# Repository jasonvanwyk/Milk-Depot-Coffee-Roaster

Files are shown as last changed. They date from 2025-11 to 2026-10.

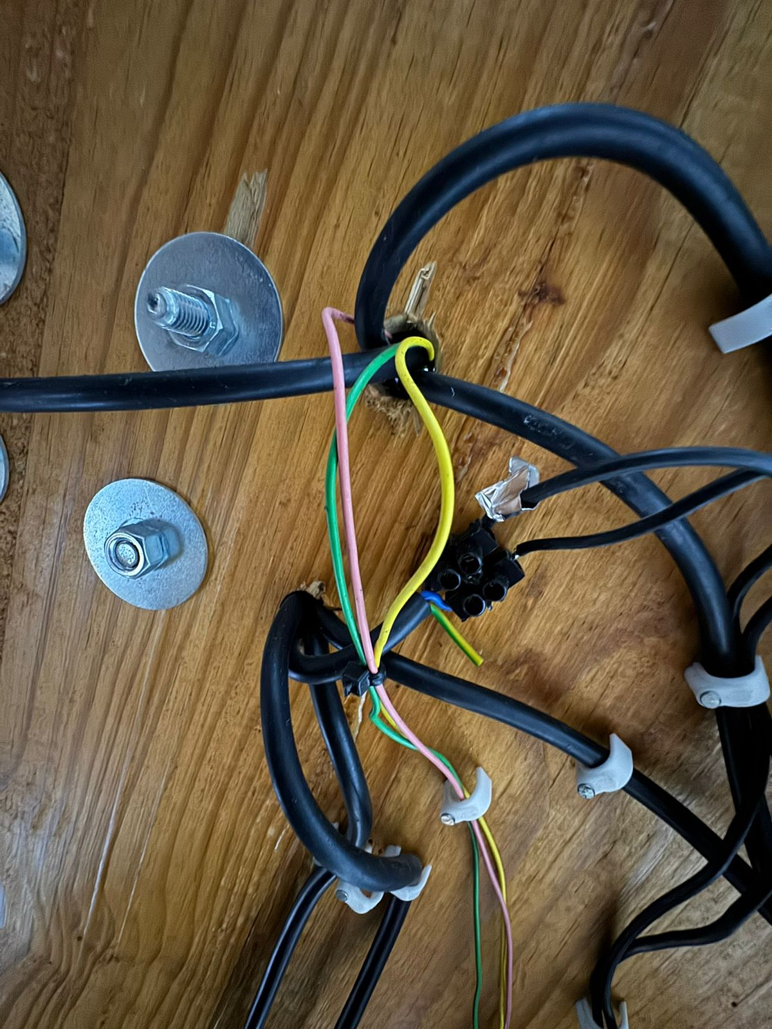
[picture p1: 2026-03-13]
pics/WhatsApp Image 2026-03-13 at 13.25.46.jpeg

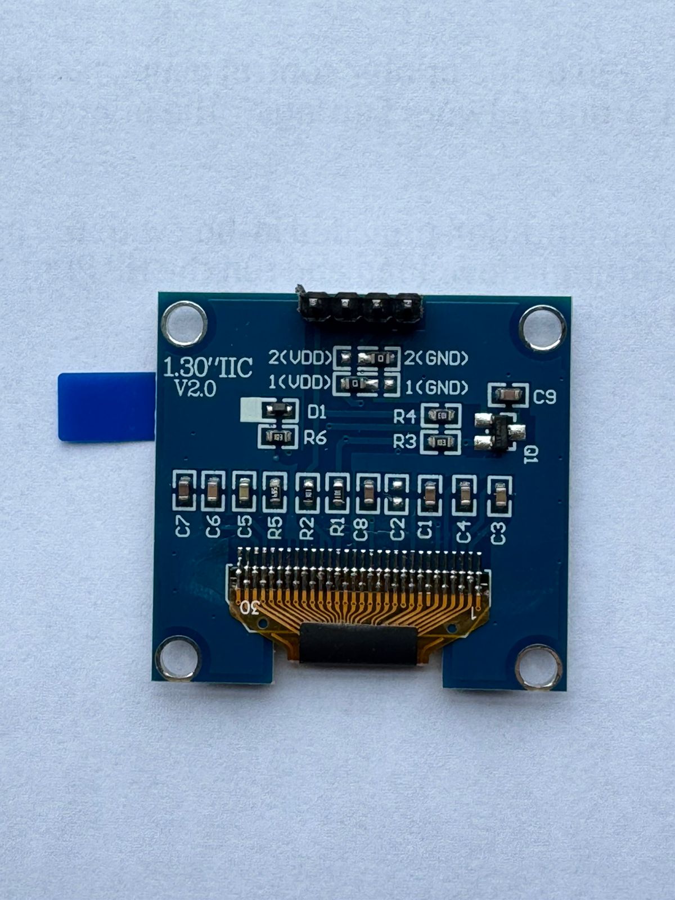
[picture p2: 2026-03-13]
pics/WhatsApp Unknown 2026-03-13 at 13.41.29/WhatsApp Image 2026-03-13 at 13.41.10.jpeg

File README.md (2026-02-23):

# Milk Depot Coffee Roaster - Precept Systems Project

## Client Information

| Field | Details |
|---|---|
| **Client Name** | Quenton (Milk Depot) |
| **Contact** | Via Jason van Wyk |
| **Project** | Coffee Roaster Temperature Monitoring System |

## Project Overview

Custom coffee roasting temperature monitoring system integrating Arduino-based 3-channel thermocouple interface with Artisan roasting software on Raspberry Pi 4. The system reads Bean Temperature (BT), Exhaust Temperature (ET), and Flame Temperature (FT) via MAX31855 amplifiers and displays real-time temperature curves with rate-of-rise calculations.

## Project Scope

1. **Arduino Firmware** - TC4 protocol emulator for 3-channel MAX31855 thermocouple reading
2. **Hardware Integration** - 3x custom K-type thermocouple probes with compression fittings, MAX31855 amplifiers, enclosure
3. **Software Configuration** - Artisan v3.4.0 setup on Raspberry Pi 4 with ArduinoTC4 device
4. **Calibration & Testing** - Probe calibration and first test roast

## Current Status

**See `STATUS.md` for detailed task tracking and current project status.**

### Quick Status
- **Phase:** Hardware Procurement
- **Software:** Complete and tested (firmware + Artisan)
- **Hardware:** Thermocouples on order from GPA Trading (PO P00041)

### Milestones
- [x] Git repository initialized
- [x] Artisan v3.4.0 installed on Raspberry Pi
- [x] Arduino TC4 firmware written and tested
- [x] Helper scripts created (compile, upload, detect, monitor)
- [x] Documentation complete
- [x] Custom thermocouple probes ordered (GPA Trading)
- [ ] Thermocouple probes delivered
- [ ] MAX31855 modules + remaining components procured
- [ ] Hardware assembly in enclosure
- [ ] Sensor calibration
- [ ] First test roast

## Hardware Summary

| Component | Status |
|---|---|
| Raspberry Pi 4 | Owned, Artisan installed |
| Arduino UNO R3 | Owned, firmware tested |
| 3x Custom K-Type Probes | On order (GPA Trading, PO P00041) |
| 3x MAX31855 Modules | To be procured |
| ABS Enclosure | To be procured |
| SSD1306 OLED (optional) | To be procured |

## Temperature Channels

| Channel | Name | Description | Artisan Mapping |
|---|---|---|---|
| 1 | ET | Exhaust/Environment Temperature | Primary ET |
| 2 | BT | Bean Temperature | Primary BT |
| 3 | FT | Flame/Burner Temperature | Extra (ArduinoTC4_34) |

## Key Files

| File | Purpose |
|---|---|
| `STATUS.md` | **Current project status and task tracking** |
| `RESUME.md` | Quick session resume context |
| `CLAUDE.md` | AI assistant project context |
| `correspondence/` | All client/supplier correspondence |
| `docs/` | Technical documentation and planning |
| `arduino-firmware/` | Arduino sketches (TC4 emulator, temp monitor, etc.) |
| `scripts/` | Helper scripts (compile, upload, detect, monitor) |

## Documentation

All technical documentation is in `docs/`:

| Document | Description |
|---|---|
| [BOM.md](docs/BOM.md) | Bill of Materials with pricing |
| [WIRING.md](docs/WIRING.md) | Wiring diagrams and enclosure layout |
| [ARTISAN_INTEGRATION.md](docs/ARTISAN_INTEGRATION.md) | Artisan configuration guide |
| [SERIAL_PROTOCOL.md](docs/SERIAL_PROTOCOL.md) | TC4 serial communication protocol |
| [ARDUINO_CLI.md](docs/ARDUINO_CLI.md) | Arduino CLI workflow guide |
| [THERMOCOUPLE_SPEC.md](docs/THERMOCOUPLE_SPEC.md) | Thermocouple technical specification |
| [CUSTOM_TC_ORDER_SPEC.md](docs/CUSTOM_TC_ORDER_SPEC.md) | Custom order spec sent to GPA Trading |
| [SHOPPING_LIST.md](docs/SHOPPING_LIST.md) | Printable shopping list with suppliers |

## Quick Start

```bash
# Compile firmware
./scripts/compile.sh arduino-firmware/tc4_emulator

# Upload to Arduino (press RESET if needed)
./scripts/upload.sh arduino-firmware/tc4_emulator

# Monitor serial output
./scripts/monitor.sh

# Detect Arduino boards
./scripts/detect.sh
```

## Workflow Notes

1. Always update `STATUS.md` when tasks are completed or status changes
2. Correspondence goes in `correspondence/` folder with date prefix
3. Technical documents go in `docs/` folder
4. Use git commits with descriptive messages

## License

- Artisan is licensed under GPL-3.0
- This project: MIT License

## Author

Jason van Wyk (jason@precept.co.za) - Precept Systems (Pty) Ltd

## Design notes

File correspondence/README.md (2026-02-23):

# Correspondence Log - Milk Depot Coffee Roaster

## Overview

This folder contains all correspondence related to the Milk Depot Coffee Roaster project, including supplier communications and client interactions.

---

## Correspondence Index

| Date | Type | Subject | Contact | File |
|---|---|---|---|---|
| 2026-01-12 | Email | Quote request for custom K-type probes | Sam Hattingh (GPA Trading) | Gmail thread |
| 2026-01-23 | Email | Quote response + acceptance | Sam Hattingh (GPA Trading) | Gmail thread |
| 2026-02-02 | Email | PO P00041 - Thermocouple order | Sam Hattingh (GPA Trading) | Gmail thread |
| 2026-02-09 | Email | Invoice + banking details reminder | Sam Hattingh (GPA Trading) | Gmail thread |

---

## File Naming Convention

- WhatsApp: `YYYY-MM-DD_whatsapp.md`
- Email: `YYYY-MM-DD_email.md`
- Phone: `YYYY-MM-DD_phone.md`
- Site Visit: `YYYY-MM-DD_site-visit.md`
- Multi-day thread: `YYYY-MM-DD-DD_channel.md`

---

## Contact Details

### Supplier: GPA Trading
- **Contact:** Sam Hattingh
- **Email:** shattingh@gpatrading.co.za
- **Role:** Thermocouple supplier (custom K-type probes)

### Client: Milk Depot
- **Contact:** Quenton
- **Role:** Coffee roaster owner/operator

---

## Notes

- Sam prefers email communication
- Quenton communicates via Jason

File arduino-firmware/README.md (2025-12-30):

# Arduino Temperature Monitor Firmware

Custom Arduino firmware for the Milk Depot Coffee Roaster - 3-channel thermocouple interface for Artisan software.

## Overview

This firmware reads temperature from three K-type thermocouples via MAX31855 amplifier modules:

| Channel | Name | Description |
|---|---|---|
| 1 | ET | Exhaust/Environment Temperature - air leaving the drum |
| 2 | BT | Bean Temperature - probe in bean mass |
| 3 | FT | Flame Temperature - near the burner |

Temperature data is sent over USB serial to Raspberry Pi running Artisan software.

## Firmware Variants

| Sketch | Protocol | Use Case |
|---|---|---|
| `tc4_emulator/` | TC4 command/response | **Production** - Use with ArduinoTC4 device |
| `temp_monitor/` | Continuous output | Alternative - Use with External Program |
| `serial_test/` | Basic serial | Testing only |
| `blank/` | None | For easy uploads when main firmware blocks |

## Hardware Requirements

### Required Components
- Arduino UNO R3
- 3x MAX31855 thermocouple amplifier modules
- 3x K-type thermocouples (Olimex TC-K-TYPE-1.5M recommended)
- USB cable for Arduino → Raspberry Pi

### Optional
- SSD1306 OLED display (128x64, I2C) for local readout

## Wiring

### SPI Bus (Shared)
```
Arduino D13 (SCK)  ────┬──── MAX31855 #1 SCK
                       ├──── MAX31855 #2 SCK
                       └──── MAX31855 #3 SCK

Arduino D12 (MISO) ────┬──── MAX31855 #1 DO
                       ├──── MAX31855 #2 DO
                       └──── MAX31855 #3 DO
```

### Chip Select (Individual)
```
Arduino D10 ──── MAX31855 #1 CS (ET - Exhaust)
Arduino D9  ──── MAX31855 #2 CS (BT - Bean)
Arduino D8  ──── MAX31855 #3 CS (FT - Flame)
```

### Power (Shared)
```
Arduino 5V  ────┬──── All MAX31855 VCC
                └──── OLED VCC (optional)

Arduino GND ────┬──── All MAX31855 GND
                └──── OLED GND (optional)
```

### I2C for OLED (Optional)
```
Arduino A4 (SDA) ──── OLED SDA
Arduino A5 (SCL) ──── OLED SCL
```

## Installation

### 1. Install Required Libraries

Open Arduino IDE → Sketch → Include Library → Manage Libraries:

- **Adafruit MAX31855** (required)
- **Adafruit BusIO** (dependency)
- **Adafruit SSD1306** (optional, for OLED)
- **Adafruit GFX Library** (optional, for OLED)

### 2. Enable Hardware Support

Edit `tc4_emulator.ino` (or `temp_monitor.ino`):

```cpp
// Uncomment this line:
#include <Adafruit_MAX31855.h>

// Uncomment thermocouple objects:
Adafruit_MAX31855 thermoET(PIN_SCK, PIN_CS_ET, PIN_MISO);
Adafruit_MAX31855 thermoBT(PIN_SCK, PIN_CS_BT, PIN_MISO);
Adafruit_MAX31855 thermoFT(PIN_SCK, PIN_CS_FT, PIN_MISO);
```

In each `readTemperature_XX()` function:
- Uncomment the MAX31855 library code block
- Delete/comment the `readAnalogSimulated()` line

### 3. Compile and Upload

From project root:
```bash
./scripts/compile.sh arduino-firmware/tc4_emulator
./scripts/upload.sh arduino-firmware/tc4_emulator
```

If upload fails (firmware blocking bootloader):
- Press Arduino RESET button immediately after starting upload
- Or upload `blank/blank.ino` first

### 4. Test

```bash
# Monitor serial output
python3 test_serial.py

# Or test TC4 protocol manually
screen /dev/ttyACM0 115200
# Type: READ
# Should see: 25.00,xxx.xx,xxx.xx,xxx.xx,0.00
```

## Serial Protocol

### TC4 Protocol (tc4_emulator)

**Command/Response format:**
```
Artisan sends:  READ
Arduino sends:  25.00,180.50,195.20,350.00,0.00
                 │     │      │      │      └── Chan4 (unused)
                 │     │      │      └── Chan3 (FT)
                 │     │      └── Chan2 (BT)
                 │     └── Chan1 (ET)
                 └── Ambient temp
```

**Supported commands:** `READ`, `CHAN`, `UNITS`, `FILT`, `OT1`, `OT2`, `PID`

### Continuous Output (temp_monitor)

```
ET:180.5,BT:195.2,FT:350.0
```
Sent every 1000ms.

### Settings
- **Baud Rate**: 115200
- **Data Bits**: 8
- **Parity**: None
- **Stop Bits**: 1

## Calibration

### Procedure

1. **Ice Water Test (0°C)**:
   - Place all probes in ice water slurry
   - Wait for readings to stabilize
   - Note offset from 0°C

2. **Update Firmware**:
   ```cpp
   float calibOffset_ET = 0.0 - reading;  // e.g., -2.3
   float calibOffset_BT = 0.0 - reading;
   float calibOffset_FT = 0.0 - reading;
   ```

3. **Verify with Boiling Water** (~96°C at Johannesburg altitude)

### Example
If ET reads 2.3°C in ice water:
```cpp
float calibOffset_ET = -2.3;
```

## Configuration

Edit constants in firmware source:

| Constant | Default | Description |
|---|---|---|
| `BAUD_RATE` | 115200 | Serial speed |
| `PIN_CS_ET` | 10 | Chip select for ET |
| `PIN_CS_BT` | 9 | Chip select for BT |
| `PIN_CS_FT` | 8 | Chip select for FT |
| `calibOffset_ET` | 0.0 | ET calibration offset |
| `calibOffset_BT` | 0.0 | BT calibration offset |
| `calibOffset_FT` | 0.0 | FT calibration offset |

## Troubleshooting

### No Data / No Response to READ
- Check baud rate (115200)
- Verify USB connection
- Check Arduino power LED
- Re-upload firmware

### "NaN" or Missing Readings
- Thermocouple not connected
- Wrong CS pin wiring
- Module not powered
- Check thermocouple polarity (red = negative for K-type)

### Noisy/Jumping Readings
- Add 0.1µF capacitor across thermocouple input
- Keep thermocouple wires away from power cables
- Use shielded cable
- Ensure good grounding

### Upload Fails
Firmware sending data blocks bootloader:
1. Start upload command
2. Immediately press Arduino RESET button
3. Bootloader has ~2 second window

Or upload `blank.ino` first.

## Safety

- K-type thermocouples rated to 700°C (well above coffee roasting temps)
- Keep electronics away from heat
- Use heat-resistant probe sheathing
- Ensure probes are food-safe (stainless steel)

## Version History

| Version | Date | Changes |
|---|---|---|
| 2.0 | 2024-12-30 | 3-channel support, MAX31855, TC4 protocol |
| 1.0 | 2024-11-10 | Initial 2-channel analog version |

## Resources

- [MAX31855 Datasheet](https://www.analog.com/media/en/technical-documentation/data-sheets/MAX31855.pdf)
- [Adafruit MAX31855 Library](https://github.com/adafruit/Adafruit_MAX31855)
- [Artisan TC4 Protocol](https://artisan-scope.org/devices/arduino/)
- [K-type Thermocouple Guide](https://learn.adafruit.com/thermocouples)

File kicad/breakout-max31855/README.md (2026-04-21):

# MD-TC-BRK v1.0 — MAX31855 K-Type Thermocouple Breakout

Custom breakout forked from **SparkFun DEV-13266** (MAX31855K Thermocouple Breakout), ported Eagle → KiCad 10 and adapted for the Milk Depot Coffee Roaster signal chain.

Client: Quenton (Milk Depot)
Design owner: Precept Systems (Pty) Ltd — Jason van Wyk
Status at creation: 2026-04-21 — **pre-import scaffold**. Eagle source vendored, KiCad project not yet generated.

## Board identity

| Field | Value |
|---|---|
| Board ID (silkscreen) | `MD-TC-BRK v1.0` |
| Project role | 1-of-3 breakouts on Nano stripboard (BT, ET, FT channels) |
| Licence | CC-BY-SA 4.0 (derivative) |
| Attribution | Fork of SparkFun DEV-13266 — https://github.com/sparkfun/Thermocouple_Breakout-MAX31855K |
| Upstream licence | CC-BY-SA 4.0 — preserved at `eagle-source/LICENSE-upstream.md` |

## Architecture context (short)

The Milk Depot roaster uses three K-type probes (Bean, Exhaust, Flame) feeding an Arduino Nano 5V via three of these breakouts on a stripboard. A dedicated NCP1117ST33T3G LDO supplies 3.3V to the breakouts from the stripboard; SPI is level-shifted by resistor dividers (SCK 1k/1.8k shared, CS 10k/18k per channel). Shields terminate at the probe end only. See `kicad-coffee-roaster` tool repo `RESUME.md` for the full locked spec.

## Repository layout

```
breakout-max31855/
├── README.md                                     ← this file
├── eagle-source/                                 ← upstream reference, DO NOT EDIT
│   ├── SparkFun_Thermocouple_Breakout.sch       ← Eagle XML — import source
│   ├── SparkFun_Thermocouple_Breakout.brd       ← Eagle board — optional PCB ref
│   └── LICENSE-upstream.md                       ← SparkFun CC-BY-SA 4.0 notice
└── (KiCad files will be generated by the import step below)
```

## KiCad 10 Eagle import — step-by-step

The import is a KiCad GUI operation; `kicad-cli` has no Eagle import in v10.0.1.

### 1. Launch KiCad and run the import

```bash
kicad   # or GDK_BACKEND=x11 kicad  if Wayland decoration clips dialogs
```

In KiCad's project manager:

1. **File → Import → Non-KiCad Project → Eagle**
2. Select source: `breakout-max31855/eagle-source/SparkFun_Thermocouple_Breakout.sch`
3. Select destination: `breakout-max31855/` (same folder as this README)
4. Project name: `breakout-max31855`
5. Click **Import**

KiCad will generate `breakout-max31855.kicad_pro`, `.kicad_sch`, `.kicad_pcb` (and possibly `.kicad_sym` / `.pretty/` for unmapped symbols/footprints).

### 2. Tell Claude to run phase-2 cleanup

Once the import finishes, return to the `kicad-coffee-roaster` tool session and say "import done, run phase 2" — Claude will:

- Set the title block (title, company, author, revision, date, comments with licence & attribution)
- Set page size to **A4 landscape**
- Link the shared custom library (`../libs/milk-depot.kicad_sym` + `../libs/milk-depot.pretty`) via the project's `sym-lib-table` / `fp-lib-table`
- Run `kicad-cli sch erc` as a post-import sanity check

## Planned forks from upstream (5 changes)

Tracked as the "design deltas" from SparkFun DEV-13266. Each is a separate working session after phase-2 cleanup completes.

- [ ] **1. Footprint swap** — MAX31855K generic → **MAX31855KASA+** (genuine Maxim SOIC-8) using the symbol in `../libs/milk-depot.kicad_sym`.
- [ ] **2. Thermocouple connector** — Replace SparkFun's `PCB_THERMOCOUPLE` pads with **DG127-5.08-02P** (Mantech 15M0713) 2-pole 5.08 mm screw terminal. Verify pin 1 orientation against Degson datasheet.
- [ ] **3. Passive upsize** — 0603 → **0805** throughout (matches DigiKey #122880837 stock convention). C1 100 nF X7R, C2 10 nF X7R, L1/L2 470 Ω @ 100 MHz, R1 10 kΩ.
- [ ] **4. DNP footprints** — Add (do-not-populate by default):
  - C3, C4 (1 nF X7R 0805) — T+/T− common-mode caps
  - D1, D2 (5.6 V bidirectional TVS, SMA/SMB) — ESD/surge clamp at screw terminal
  - M3 chassis-bond mounting hole: 10 nF Y1 cap + 1 MΩ bleed resistor (both DNP for soft-bond option at bring-up)
- [ ] **5. Silkscreen + title block** — Board ID, attribution, licence, polarity warnings per locked spec:
  - `MD-TC-BRK v1.0`
  - `CC-BY-SA 4.0 / fork of SparkFun MAX31855K`
  - `Red = NEGATIVE` next to DG127 terminal
  - `+` / `−` markers on DG127 pads
  - `3.3V ONLY` next to VCC pin on JP1 header
  - Pin 1 dot on U1, JP1, J1

## Mechanical targets

- Screw terminal J1 on one long edge, 6-pin header JP1 on the opposite long edge, 20–25 mm apart.
- Preserve SparkFun's JP1 pinout exactly: `GND, VCC, SCK, MISO, NC, CS` — this keeps compatibility with SparkFun's reference wiring diagrams and any DEV-13266 sockets on the stripboard.
- 4× unplated M3 mounting holes (check clearance against the DG127 body and U1).
- Target PCB: 2-layer, JLCPCB-standard (6 mil/6 mil trace/space, 0.3 mm via).

## Bring-up plan (for later reference)

Once fabbed, a genuine **SparkFun DEV-13266** (~$15, to be ordered) acts as the golden reference. First power-up reads the same K-type probe on both boards in parallel; agreement within 0.5°C validates our fork.

## Related docs (outside this folder)

- `../../docs/BOM.md` — project-wide BOM (will need update to carry MD-TC-BRK v1.0 line items at fab time)
- `../../docs/THERMOCOUPLE_SPEC.md` — K-type probe spec, GPA Trading PO P00041
- `~/tools/kicad-coffee-roaster/` — design companion tool repo, holds prior-art research, reference designs (including Adafruit for comparison), and the locked electrical spec
- `~/tools/kicad-coffee-roaster/docs/reference-designs/sparkfun-max31855k/` — full vendored SparkFun upstream (Hardware, Libraries, README, LICENSE)

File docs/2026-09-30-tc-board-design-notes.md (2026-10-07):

# 4-Channel Isolated Thermocouple Board — Design Notes

Decided 30 September 2026. One board carries four isolated MAX31855 channels (three fitted: BT, ET, FT) and connects to a LilyGO T-Display-S3. These notes are the input for the schematic; they supersede the single-breakout v1.0/v1.1 guide in `kicad/breakout-max31855/schematic-guide.md` wherever the two disagree.

## Why each channel has its own isolated island

All six probes are grounded-junction (DMM test, April 2026), so every probe tip is joined to the others through the roaster chassis. The MAX31855 connects T− to its own ground through an internal switch during conversion and opens that switch during fault detection (datasheet, "Conversion Functions"). On a shared island, a chip in its fault-detection phase would see T− tied to ground through a neighbouring chip and report a short-to-GND fault. This is inferred from the datasheet, not bench-tested. Separate islands remove the path entirely.

## Per channel (isolated side, nets suffixed `_ISO`)

- RFB-0505S isolated DC-DC: host 5V in, `+5V_ISO` out. Output runs above 5V at light load (load regulation is only specified from 10%).
- NCP1117ST33T3G: `+5V_ISO` → `+3V3_ISO`. Output capacitor must be the 10 µF tantalum (TPSB106K016R0800, ESR 0.8 Ω max); the regulator needs 0.033–2.2 Ω ESR and 0805 ceramics are too low. Stripe on the tantalum = positive.
- MAX31855KASA+ with 100 nF decoupling and 10K CS pull-up to `+3V3_ISO`.
- ISO7731DWR island side powered from `+3V3_ISO` (not from the DC-DC output).
- 10K pull resistor on `MISO_ISO`: the MAX31855 SO pin is high-impedance when CS is high, so the isolator input must not float.
- Input filter and protection per probe line: ferrite BLM21AG471SN1D in series on T+ and T−, 10 nF across T+/T−, 1 nF from each line to `GND_ISO`, SMAJ5.0CA from each line to `GND_ISO`. The TVS can leak up to 1.6 mA at 5V; it only sees millivolts here, but it is the first suspect if false faults appear at bring-up.
- DG127-5.08-02P screw terminal. Pin 1 = T+, pin 2 = T−. K-type red wire is negative.
- Chassis network (mounting hole, solder jumper, 10 nF 630V, 1 MΩ): **left out, decided 7 October 2026.** The probes are grounded-junction, so each island is already referenced to the roaster body through its probe; closing the jumper would put T− to island ground in parallel with that and give a constant short-to-GND fault, so the jumper could never be closed. The plastic enclosure has no chassis to bond to, and the ferrite / TVS / 1 nF input filters cover the noise role. Mounting holes are plain, unconnected. **Caveat for a future revision:** if insulated-junction probes are ever fitted, the islands float and a bleed network (1 MΩ + 10 nF 630 V from island ground to a chassis point) becomes worth having. The RC0805FR-071ML and C0805C103KBRACAUTO parts from the 30 September order are on hand for that.

## Host side (shared by all channels)

- 5V from the T-Display-S3 5V pin feeds the four DC-DC inputs (each draws 25–30 mA idle, about 120 mA total) with 10 µF + 100 nF at the entry.
- 3.3V from the T-Display-S3 feeds the host side of every ISO7731 and the SN74AHC125, so nothing driven back to the ESP32 exceeds 3.3V.
- SN74AHC125DR quad buffer: each channel's isolator MISO output goes through one buffer whose active-low enable is that channel's CS. Without it, four isolator outputs would drive the shared MISO line at once.
- ISO7731 (non-F) outputs default high if the input side loses power, which keeps each MAX31855 deselected.
- Host connector: GND, +5V, +3V3, SCK, MISO, CS1, CS2, CS3, CS4.

## ISO7731DWR pinout (SOIC-16 wide)

| Pin | Name | Pin | Name |
|---|---|---|---|
| 1 | VCC1 | 16 | VCC2 |
| 2 | GND1 | 15 | GND2 |
| 3 | INA | 14 | OUTA |
| 4 | INB | 13 | OUTB |
| 5 | OUTC | 12 | INC |
| 6 | NC | 11 | NC |
| 7 | EN1 | 10 | EN2 |
| 8 | GND1 | 9 | GND2 |

From `docs/parts-specs/iso7730.pdf` Figure 4-2. Side 1 = host (SCK and CS in on A/B, MISO out on C). Side 2 = island. EN pins are active high and may be left open.

## RFB-0505S pinout (SIP7)

Pin 1 +Vin, pin 2 −Vin, pin 4 −Vout, pin 6 +Vout. 19.6 × 6.0 × 10.2 mm. 1 kVDC functional isolation.

## DigiKey order — placed and paid 30 September 2026

Enough for two boards (eight channels).

| MPN | DigiKey PN | Qty | Use |
|---|---|---|---|
| ISO7731DWR | 296-44899-1-ND | 10 | Digital isolator, one per channel |
| RFB-0505S | 945-3158-ND | 8 | Isolated DC-DC, one per channel (no spares) |
| SN74AHC125DR | 296-4530-1-ND | 10 | MISO buffer, one per board |
| TPSB106K016R0800 | 478-2398-1-ND | 20 | 10 µF tantalum, regulator output |
| BLM21AG471SN1D | 490-1039-1-ND | 20 | Ferrite, two per channel |
| CL21B102KBANNNC | 1276-1020-1-ND | 20 | 1 nF, two per channel |
| SMAJ5.0CA-13-F | SMAJ5.0CA-FDICT-ND | 20 | TVS, two per channel |
| RC0805FR-071ML | 311-1.00MCRCT-ND | 10 | 1 MΩ bleed |
| C0805C103KBRACAUTO | 399-C0805C103KBRACAUTOCT-ND | 20 | 10 nF 630V, optional fit |

All nine datasheets are in `docs/parts-specs/` and were checked against the order. Already on hand: MAX31855KASA+ ×9, NCP1117ST33T3G ×10, DG127 screw terminals ×15, 0805 10K / 100 nF / 10 nF / 10 µF, pin headers.

## Still to buy

- ~~LilyGO T-Display-S3, non-touch~~ — ordered 30 September 2026: 1× with unsoldered pins from the LilyGO Official Store on AliExpress, ref 3076608492140357, R373.98 including shipping. A second as a spare is optional (Micro Robotics lists it at R315.00 ex VAT, no stock on 30 September 2026).
- ~~Panel-mount push button for cycling display pages~~ — ordered 2 October 2026: 10× 16 mm flat-head metal, momentary, 1NO, no LED, pre-wired, AliExpress ref 3076815630860357. Needs a 16 mm panel hole. Wire to a spare T-Display-S3 pin and GND through a 2-pin connector on this board; internal pull-up in firmware.
- ~~Spare RFB-0505S~~ — bought.
- Connector and cable between the board and the T-Display-S3, chosen at layout time.
- PCBs from JLCPCB once the layout is done.

## Corrections to the April 2026 notes in `~/tools/kicad-coffee-roaster/`

- ISO7421 was named as the isolator; it has only two channels. Three are needed.
- NMA0505SC was named as a DC-DC candidate; it is a dual-output part.
- Three breakouts sharing one MISO line would have clashed; the quad buffer fixes this.
- 3 kV isolation was specified; the fitted DC-DC is 1 kV functional, which is sufficient for ground-loop and ignition-noise isolation (this is not a mains safety barrier).

## Footprint check before layout (7 October 2026)

Each provisional footprint was compared with the part drawing. Pad positions and drills are the pass/fail items; body outlines matter only for placement.

| Ref | Part | Footprint | Result |
|---|---|---|---|
| PS101–PS401 | RFB-0505S (SIP7, pins 1/2/4/6) | `Converter_DCDC_TRACO_TMA-05xxS_12xxS_Single_THT` | **Pass.** Pads at 0 / 2.54 / 7.62 / 12.7 mm, 1.0 mm drill, exactly the RFB recommended footprint. Body outline 19.7 × 6.3 mm vs 19.6 × 6.0 mm, pin 1 2.2 mm from the end vs 2.0 mm. Keep. |
| J2 | Button, JST PH 2-pin (B2B-PH-K-S) | `JST_PH_B2B-PH-K_1x02_P2.00mm_Vertical` | **Pass.** 2.0 mm pitch, 0.75 mm drill for the 0.7 mm hole JST specifies. Keep. |
| J1 | Host, 1×10 header | `PinHeader_1x10_P2.54mm_Vertical` | **Placeholder.** Correct for a plain header; replace once the board-to-display cable is chosen. |
| J101–J401 | DG127-5.08-02P screw terminal | `PhoenixContact_MSTBA_2,5_2-G-5,08_1x02_P5.08mm_Horizontal` | **Pads pass, outline wrong.** 5.08 mm pitch and 1.4 mm drill match the DG127 drawing. The Phoenix body is drawn 12 mm deep (2 mm behind the pin row, 10 mm to the wire face); the DG127 is 8.1 mm deep (3.9 mm behind the pins, 4.2 mm to the wire face). Replaced by `milk-depot:Degson_DG127-5.08-02P_1x02_P5.08mm_Horizontal` (true 10.16 × 8.1 mm outline, pin row 3.9 mm from the back edge and 4.2 mm from the wire face, box 3D model in `kicad/libs/milk-depot.3dshapes/`). Assign it to J101 in `channel.kicad_sch`; the four instances follow. |
| C108–C408 | TPSB106K016R0800 (B case) | `CP_EIA-3528-21_Kemet-B` | Pass. |
| D101–D402 | SMAJ5.0CA-13-F | `D_SMA` | Pass. |
| FB101–FB402 | BLM21AG471SN1D | `L_0805_2012Metric` | Pass (BLM21 is 0805). |

Everything else is 0805, SOIC-8, SOIC-14, SOIC-16W or SOT-223 and matches the ordered MPNs.

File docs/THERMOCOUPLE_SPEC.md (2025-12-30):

# Thermocouple Specification for Coffee Roasting

Technical specification for K-type thermocouple probes suitable for the Milk Depot Coffee Roaster temperature monitoring system.

## Application Overview

**Use Case**: Coffee drum roaster temperature monitoring
**Environment**: Hot air (up to 300°C), contact with coffee beans, food-safe requirement
**Integration**: MAX31855 thermocouple amplifier → Arduino → Artisan software

**Three probes required:**

| Probe | Location | Measures | Typical Range |
|---|---|---|---|
| BT (Bean Temperature) | Inside drum, in bean mass | Coffee bean temperature | 20-230°C |
| ET (Exhaust Temperature) | Exhaust duct | Air leaving drum | 20-280°C |
| FT (Flame Temperature) | Near burner | Heat source temperature | 50-400°C |

---

## Detailed Specification (For Custom Manufacturer)

### General Requirements

| Parameter | Specification | Notes |
|---|---|---|
| **Thermocouple Type** | K-Type (Chromel/Alumel) | ANSI/IEC 60584 |
| **Accuracy Class** | Class 1 or Class 2 | ±1.5°C or ±2.5°C |
| **Temperature Range** | -50°C to +500°C minimum | 700°C preferred for safety margin |
| **Quantity** | 3 probes | BT, ET, FT |

### Probe Sheath (Critical)

| Parameter | Specification | Reason |
|---|---|---|
| **Style** | Insertion/Immersion probe | Must penetrate into bean mass |
| **Material** | AISI 316 Stainless Steel | Food-safe, corrosion resistant |
| **Diameter** | 3.0mm (preferred) | Fast response, durable. Range: 2-4mm acceptable |
| **Length** | 100-150mm | Deep enough for drum insertion |
| **Tip Style** | Closed, rounded or pointed | Sealed, no exposed wires |

**Why 3mm diameter?**
- Thinner = faster response (critical for tracking roast dynamics)
- 1.5-2mm: Very fast but fragile
- 3mm: Good balance of speed and durability
- 5-6mm: Too slow, causes "thermal lag" in readings

### Junction Type

| Parameter | Specification | Notes |
|---|---|---|
| **Junction** | Grounded (preferred) | Faster response (~2s vs ~5s ungrounded) |
| **Alternative** | Ungrounded acceptable | If electrical noise is a concern |

**Grounded**: Junction welded to sheath tip - faster heat transfer
**Ungrounded**: Junction insulated from sheath - electrically isolated but slower

### Cable/Lead Wire

| Parameter | Specification | Notes |
|---|---|---|
| **Length** | 1.5-2.0 meters | Reach from roaster to electronics enclosure |
| **Insulation** | Fiberglass or PTFE | High temperature rated |
| **Shielding** | Stainless steel overbraid | EMI protection, mechanical protection |
| **Temperature Rating** | 350°C minimum at probe end | Cable can be cooler further from probe |

### Connector

| Parameter | Specification | Notes |
|---|---|---|
| **Type** | Miniature K-type flat blade | ANSI standard, yellow color code |
| **Pin Spacing** | 7.16mm (0.282") center-to-center | Standard miniature TC connector |
| **Gender** | Male plug on cable end | Mates with MAX31855 module socket |

**Connector Diagram:**
```
    ┌─────────────┐
    │  YELLOW     │  ← K-type color code (ANSI)
    │   ┌───┐     │
    │   │ + │     │  ← Larger pin (positive, Chromel)
    │   └───┘     │
    │   ┌───┐     │
    │   │ - │     │  ← Smaller pin (negative, Alumel)
    │   └───┘     │
    └─────────────┘
       Male plug
```

### Mounting (Optional)

| Parameter | Options | Notes |
|---|---|---|
| **Thread** | M6 x 1.0 or M8 x 1.25 | For fixed mounting through roaster wall |
| **Compression Fitting** | 1/8" or 6mm | Adjustable depth |
| **None** | Probe only | Will fabricate own mounting |

For this project: **No mounting hardware required** - will fabricate custom mounting brackets.

---

## Performance Requirements

| Parameter | Requirement | Test Method |
|---|---|---|
| **Response Time (t90)** | ≤5 seconds in moving air | Step change in air temperature |
| **Accuracy at 200°C** | ±2.5°C or better | Calibrated reference |
| **Repeatability** | ±0.5°C | Multiple measurements |
| **Long-term Drift** | <1°C/year | - |

### Response Time Guidance

| Probe Diameter | Approximate t90 (air) | Approximate t90 (liquid) |
|---|---|---|
| 1.5mm | 2-3 seconds | <1 second |
| 3.0mm | 4-6 seconds | 1-2 seconds |
| 6.0mm | 10-15 seconds | 3-5 seconds |

*t90 = time to reach 90% of final temperature*

---

## Summary Specification Table

**For quoting purposes - provide this to suppliers:**

| Item | BT Probe | ET Probe | FT Probe |
|---|---|---|---|
| **Type** | K-Type Thermocouple | K-Type Thermocouple | K-Type Thermocouple |
| **Sheath Material** | 316 Stainless Steel | 316 Stainless Steel | 316 Stainless Steel |
| **Sheath Diameter** | 3.0mm | 3.0mm | 3.0mm |
| **Sheath Length** | 100mm | 100mm | 150mm |
| **Junction** | Grounded | Grounded | Grounded |
| **Cable Length** | 1.5m | 1.5m | 1.5m |
| **Cable Insulation** | Fiberglass + SS braid | Fiberglass + SS braid | Fiberglass + SS braid |
| **Connector** | Miniature K-type male | Miniature K-type male | Miniature K-type male |
| **Temp Range** | -50 to +500°C | -50 to +500°C | -50 to +700°C |
| **Mounting** | None (bare probe) | None (bare probe) | None (bare probe) |

**Quantity: 3 probes total (1 of each)**

---

## What NOT to Order

Avoid these styles - they won't work for coffee roasting:

| Style | Why Not Suitable |
|---|---|
| Surface/Washer/Ring mount | Measures surface temp, not insertion |
| Exposed junction (bare wires) | Fragile, not food-safe |
| Air temperature probes (with handle) | Handle melts, wrong form factor |
| Pipe clamp style | Wrong application |
| Very thick probes (>6mm) | Too slow response time |

---

## Reference Standards

- **IEC 60584-1**: Thermocouple reference tables (Type K)
- **IEC 60584-2**: Thermocouple tolerances
- **ASTM E230**: Standard specification for thermocouples
- **ANSI MC96.1**: Temperature measurement thermocouples (color codes)

---

## Ordering Checklist

When ordering, confirm:

- [ ] K-type thermocouple (Chromel/Alumel)
- [ ] Insertion/immersion probe style (NOT surface mount)
- [ ] 316 stainless steel sheath
- [ ] 3mm diameter (2-4mm acceptable)
- [ ] 100-150mm probe length
- [ ] Grounded junction
- [ ] 1.5m+ cable with fiberglass/SS braid insulation
- [ ] Miniature K-type connector (male, yellow)
- [ ] Food-safe materials
- [ ] Temperature rating to at least 400°C

---

## Supplier Communication Template

**Email template for requesting quotes:**

```
Subject: Quote Request - K-Type Thermocouple Probes for Coffee Roaster

Dear [Supplier],

I require 3x K-type thermocouple probes for a coffee roasting application.

Specifications:
- Type: K-type thermocouple
- Probe style: Insertion/immersion (stainless steel sheath with closed tip)
- Sheath material: AISI 316 stainless steel (food-safe)
- Sheath diameter: 3.0mm (±0.5mm acceptable)
- Sheath length: 100-150mm
- Junction type: Grounded
- Cable length: 1.5 meters minimum
- Cable: Fiberglass insulated with stainless steel overbraid
- Connector: Miniature K-type male plug (ANSI yellow)
- Temperature range: -50°C to +500°C minimum
- Mounting: None required (bare probe)

Application: Coffee drum roaster, measuring bean mass temperature (up to 230°C),
exhaust air temperature (up to 280°C), and burner area temperature (up to 400°C).
Food-safe materials required.

Please provide:
1. Unit price for 3 probes
2. Lead time
3. Datasheet or drawing
4. Any MOQ requirements

Thank you,
[Your name]
```

---

*Document Version: 1.0*
*Date: December 2024*
*Project: Milk Depot Coffee Roaster*

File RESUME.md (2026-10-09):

# Project Resume

## Right Now
**Phase:** Development — 4-channel isolated thermocouple board: fully routed (islands + host), 0 unconnected, DRC and independent audits clean; silk tidy and review next. LilyGO T-Display-S3 is the controller + display.

**Last (9 Oct 2026, hot plate):** Chose and ordered the reflow hot plate so it arrives before the PCBs.
- `/cheap-research` (3 Sonnet agents) → `docs/research/2026-10-09-hot-plate-{requirements,products-sa,reflow-process}.md`. Key finding: the 96 × 66 mm board with pours on both layers needs a plate that overhangs it on all sides, so every SA-stocked plate (MHP30/MHP50/HT-P1A, 30–50 mm) is out.
- Compared four AliExpress 946C listings in Chrome (seller rating, stated specs, shipping). Ordered **UYUE 946C 200 × 200 mm, 600 W, 220 V EU plug** from Caius Store, ref 3076880346740357, R2,556.99 (R556 + R2,000.99 courier), due 22 Oct 2026. Fit an earthed IEC lead, bin the supplied adapter.
- Reflow oven considered and rejected for 2–5 single-sided boards; T-962 would need firmware + insulation mods.
- Follow-ups: leaded Sn63/Pb37 paste syringe (SA stock unverified — Communica or DigiKey ZA), add unframed stainless stencil to the JLCPCB order, K-type or IR thermometer for board temp.
**Next:**
1. **Start here:** Jason opens the board, eyeballs the host strip, runs DRC in the GUI once. Then silk tidy: 37 overlaps, 39 refs over copper (C_01/C_03/C_05, U_03, U1, J1), 9 silk items within 0.5 mm of slots (J_01 and PS_01 outlines, J2 label).
2. `/pcb-review-engineer`, then order from JLCPCB. Re-run `geom-audit.py` + `zone-audit.py` after any copper edit.
3. When the T-Display-S3 arrives, bench-test USB serial with Artisan on the Pi (not a blocker).

**Blocked:** Nothing. DigiKey and three AliExpress deliveries still in transit (hot plate due ~22 Oct, buttons due ~28 Oct 2026).

## Quick Context
- Client: Quenton (Milk Depot) — coffee roaster temperature monitoring
- **Signal chain:** 3 probes → 4-channel isolated board → T-Display-S3 (own 1.9" screen + page button) → USB → Raspberry Pi 4 running Artisan → HMI screen (already owned)
- **Probes are grounded-junction** — per-channel isolation is required whatever the controller. Possibly what killed the first prototype's MAX31855.
- **Schematic rule:** power symbols (`+5V`, `+3V3`, `GND`) only on the host side. Island nets are local labels, so each channel gets its own copy.
- **How Claude checks:** copy board to scratchpad, `kicad-cli pcb drc --refill-zones --save-board --severity-all` and `kicad-cli pcb export svg` on the saved board; parse pad positions from the `.kicad_pcb`. Never edit the board while KiCad has it open; bulk edits only with the editor closed and a backup in the scratchpad. **For routing: generate geometry by script and let DRC judge it — never work clearances out in reasoning.**
- **T-Display-S3:** 1.9" IPS, 6 clean spare pins + 5V pin, native USB. Glance display with pages cycled by a panel button.
- **USB plan:** firmware in TinyUSB CDC mode with `enableReboot(false)`; fallback is UART0 through a USB-serial adapter.
- **Orders in transit (all paid):** DigiKey isolation parts (30 Sep 2026); T-Display-S3, AliExpress ref 3076608492140357; panel buttons, AliExpress ref 3076815630860357, estimated 28 Oct 2026; UYUE 946C hot plate (200 mm, 220 V), AliExpress ref 3076880346740357, R2,556.99, ordered 9 Oct 2026, estimated 22 Oct 2026. Use leaded Sn63/Pb37 paste + JLCPCB stencil (see `docs/research/2026-10-09-hot-plate-reflow-process.md`).
- **No longer in the design:** Arduino Nano + stripboard, MD0074 20×4 LCD, BSS138 level shifters, full-system ESP32 PCB, `kicad/breakout-max31855/`.
- RPi 4 via SSH at 10.0.10.102 (user: jason, key-based auth)

## Development Plan
1. ~~Probes delivered and confirmed grounded-junction~~ ✓
2. ~~Choose controller + display~~ ✓ T-Display-S3
3. ~~Order isolation parts, T-Display-S3 and panel buttons~~ ✓
4. ~~4-channel schematic, ERC clean~~ ✓ 7 Oct 2026
5. PCB layout: ~~placement, slots, holes, ground zones, island routing, host routing~~ ✓ 8 Oct 2026 → silk tidy, review, order from JLCPCB
6. Hand-assemble the board
7. Port firmware to ESP32-S3: 3 channels, display pages, page button, TC4 protocol
8. Design and print the enclosure
9. Clone repo to RPi properly
10. Calibrate (ice water + boiling water)
11. Mount probes in roaster, first test roast with Artisan

## Key Files
- `kicad/tc-board-4ch/tc-board-4ch.kicad_pcb` — the board, fully routed, 0 unconnected; `.kicad_dru` — isolation DRC rules; `.kicad_pro` — net classes
- `kicad/tc-board-4ch/host-routing.py` — host routing generator (moves + tracks + vias), run as `python3 -I host-routing.py in.kicad_pcb out.kicad_pcb`
- `docs/2026-10-08-host-routing-plan.md` — move table, lane table, per-net step list (applied 8 Oct 2026)
- `kicad/tc-board-4ch/geom-audit.py`, `zone-audit.py` — independent clearance audits, second opinion to DRC; run after any copper edit
- `kicad/tc-board-4ch/tc-board-4ch.kicad_sch` + `channel.kicad_sch` — schematic, ERC clean
- `kicad/libs/milk-depot.kicad_sym` — custom symbols; `milk-depot.pretty/` — DG127 footprint
- `docs/2026-09-30-tc-board-design-notes.md` — design rules, pinouts, order, footprint check, chassis decision
- `arduino-firmware/tc4_emulator/tc4_emulator.ino` — Nano firmware, to be ported
- `docs/BOM.md`, `docs/WIRING.md` — stale (pre-isolation, pre-T-Display-S3)
- `docs/archive/SESSION-INDEX.md` — older sessions

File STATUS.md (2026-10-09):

# Project Status - Milk Depot Coffee Roaster

**Last Updated:** 2026-10-09
**Quote Ref:** PO P00041 (thermocouples)
**Status:** Development
**Payment Terms:** Invoice on delivery (GPA Trading)

---

## Current Phase: Development

**DIRECTION RESET (30 September 2026).** Controller and display: LilyGO T-Display-S3. Thermocouple front end: one custom 4-channel board (3 fitted), each channel galvanically isolated, because the probes are grounded-junction. Everything in one custom 3D-printed enclosure. The Pi + HMI running Artisan is unchanged. The Nano/stripboard plan, the 20×4 LCD and the full-system ESP32 PCB are dropped. Isolation parts ordered and paid (DigiKey, 30 September 2026). T-Display-S3 and panel buttons ordered and paid (AliExpress, 30 September and 2 October 2026). Schematic drawn 2–7 October 2026 in `kicad/tc-board-4ch/` and ERC-clean on 7 October 2026; footprints checked and chassis network dropped the same day. PCB layout started 8 October 2026: board setup, custom isolation DRC rules, all 82 parts placed, eight isolation slots and four mounting holes in, five ground zones (host + 4 islands, both layers) filled, DRC clean on copper; islands and host fully routed (0 unconnected), DRC and two independent clearance audits clean; silk tidy and review next. Design notes: `docs/2026-09-30-tc-board-design-notes.md`.

---

## Task Status

### Completed

| Task | Completed | Notes |
|---|---|---|
| Git repository setup | 2024-12-30 | GitHub remote configured |
| Artisan v3.4.0 installation | 2024-11-10 | On Raspberry Pi 4 |
| Arduino TC4 firmware | 2024-12-30 | 3-channel MAX31855 support |
| Helper scripts | 2024-12-30 | compile, upload, detect, monitor |
| Serial communication verified | 2025-11-10 | 115200 baud, TC4 protocol working |
| Technical documentation | 2024-12-30 | BOM, wiring, protocol, specs |
| Thermocouple specification | 2026-01-12 | Custom probe specs finalized |
| Quote from GPA Trading | 2026-01-23 | 6 probes quoted, pricing accepted |
| PO P00041 placed | 2026-02-02 | Thermocouples ordered |
| Thermocouple delivery | 2026-03-13 | 6x custom K-type probes received |
| Invoice + payment | 2026-02-24 | Invoice received, POP sent same day |
| All BOM components procured | 2026-03-13 | Thermocouples from GPA, rest locally |
| KiCad tooling installed | 2026-03-13 | MCP servers + skills for schematic/PCB design |
| RPi SSH access | 2026-03-13 | 10.0.10.102, user jason, key-based auth |
| KiCad schematic created | 2026-03-13 | Arduino Nano, 2x MAX31855, OLED, 100nF caps |
| OLED bezel designed | 2026-03-13 | OpenSCAD snap-fit bezel (`3d-prints/oled-bezel.scad`) |
| OpenSCAD bezel rendered | 2026-03-13 | STL exported (25KB), PNG previews from 4 angles |
| FreeCAD bezel redesign | 2026-03-13 | Manual design with real caliper measurements (WIP) |
| WireViz installed | 2026-03-13 | v0.4.1, for wiring diagram generation |
| WireViz wiring diagram | 2026-03-17 | YAML source + PNG/SVG/HTML output with BOM |
| Fritzing breadboard layout | 2026-03-17 | Nano + 2x MAX31855 + OLED + caps, verified |
| WIRING.md rewrite | 2026-03-17 | Updated from 3-channel UNO to 2-channel Nano |
| OLED 5V confirmed | 2026-03-17 | Onboard voltage regulator visible on PCB back |
| Firmware updated for Nano 2-channel | 2026-03-18 | TC4 protocol + SH1106 OLED + MAX31855 hardware |
| First power-up test | 2026-03-18 | Firmware works, OLED works, knockoff MAX31855 smoked |
| Redesign decision | 2026-03-18 | ESP32 + genuine MAX31855 ICs + custom PCB + 2.42" OLED |
| Component sourcing | 2026-03-18 | DigiKey ZA (MAX31855KASA+) + Mantech (ESP32 KS5019) |
| BOM v2.0 rewrite | 2026-03-20 | ESP32 redesign, specific 0805 MPNs, DigiKey order checklist |
| DigiKey cart cross-reference | 2026-03-20 | All passives confirmed in Fairfield combined order |
| OLED display selected | 2026-03-20 | Adafruit 2719 (SSD1305), DigiKey 1528-1591-ND — superseded by LCD |
| Display switched to LCD | 2026-03-23 | Keyestudio MD0074 20×4 I2C LCD (Mantech 15M8244, R184.47 ex-VAT) |
| BSS138 level shifters added | 2026-03-23 | BSS138CT-ND × 4, for 3.3V↔5V I2C on custom PCB |
| PCB strategy decided | 2026-03-23 | MAX31855 breakout board first, then full system PCB |
| DigiKey unified order placed | 2026-03-28 | Via Fairfield project (FD-PROC-010), roaster parts included |
| KiCad 10 project scaffolded | 2026-03-28 | New project with JLCPCB design rules, old schematic archived |
| Schematic symbols placed | 2026-03-30 | ESP32, 2× MAX31855, 2× BSS138 — validated against datasheets |
| BSS138 sourced from Mantech | 2026-03-30 | Stock 35M3468, R1.20 each (ON Semi, SOT-23) |
| 4-channel board schematic | 2026-10-07 | `kicad/tc-board-4ch/`, root + channel sheet ×4, ERC 0 violations |
| Footprint check + chassis decision | 2026-10-07 | DG127 footprint added to `kicad/libs/milk-depot.pretty/`; chassis network left out (grounded probes) |
| PCB placement, slots, holes | 2026-10-08 | 96 × 66 mm 2-layer, 82 parts placed by script, isolation DRC rules, 0 copper violations |
| Ground zones | 2026-10-08 | Host GND + 4 GND_ISO islands, both layers, fills verified by SVG, 0 isolation violations |
| Island routing | 2026-10-08 | All 4 islands routed in the GUI, 8 vias each, +5V_ISO 0.4 mm, 0 copper violations, unconnected 137 → 37 (host only) |
| Host routing plan | 2026-10-08 | `kicad/tc-board-4ch/host-routing.py` + `docs/2026-10-08-host-routing-plan.md`; 5 part moves, 75 tracks, 37 vias; DRC-clean on scratch copy |
| Host routing applied + verified | 2026-10-08 | Script applied to the real board: 0 unconnected, 0 copper errors. Netlist 276/276, net classes clean, isolation rules proven by planted tracks, gaps 2.0/3.0 mm measured, `geom-audit.py` + `zone-audit.py` 0 violations |

### Session Completed Items (9 Oct 2026 — hot plate)
- [x] ~~Hot plate research: requirements, SA sourcing, reflow process (`docs/research/2026-10-09-hot-plate-*.md`)~~
- [x] ~~UYUE 946C 200 mm hot plate ordered from AliExpress, ref 3076880346740357, due 22 Oct 2026~~
- [ ] Leaded Sn63/Pb37 paste, stencil with JLCPCB order, board thermometer
- [ ] GUI DRC run, silk tidy (85 warnings)
- [ ] `/pcb-review-engineer`, JLCPCB order

Older sessions: `docs/archive/SESSION-INDEX.md`.

### In Progress

| Task | Status | Notes |
|---|---|---|
| DigiKey orders shipped & received | DONE | #122880837 (37 items) + #123184654 (ICs). All roaster parts on hand. |
| Mantech LCD + screw terminals received | DONE | #178252 (MD0074 LCD) + #210901 (DG127 terminals, headers) |
| BSS138 from Mantech | NOT NEEDED | Dropped from design — digital isolators handle the voltage levels |
| Full-system ESP32 schematic | ABANDONED | Replaced by T-Display-S3 + isolated breakouts |
| Isolation parts order (DigiKey) | ORDERED + PAID | 30 Sep 2026. 9 lines, enough for 2 boards. Awaiting delivery |
| T-Display-S3 order (AliExpress) | ORDERED + PAID | 30 Sep 2026. 1× non-touch, unsoldered pins, LilyGO Official Store, ref 3076608492140357, R373.98 incl. shipping. Awaiting delivery |
| Panel buttons order (AliExpress) | ORDERED + PAID | 2 Oct 2026. 10× 16 mm flat-head momentary 1NO, no LED, pre-wired, DIANQI Electric Official Store, ref 3076815630860357, R329.00. Estimated delivery 28 Oct 2026 |
| Hot plate order (AliExpress) | ORDERED + PAID | 9 Oct 2026. UYUE 946C 200×200 mm, 600 W, 220 V EU plug, Caius Store, ref 3076880346740357, R2,556.99 incl. R2,000.99 shipping (VAT/duties may follow on import). Estimated delivery 22 Oct 2026. Research: `docs/research/2026-10-09-hot-plate-*.md` |
| Spare RFB-0505S | BOUGHT | Supplier and quantity not recorded |
| Buy remaining parts | TODO | Optional second T-Display-S3. Display cable: 10-way Dupont ribbon, no purchase needed |
| Bench-test T-Display-S3 USB with Artisan | TODO | Not a blocker; firmware fix and UART fallback known |
| Footprint check before layout | DONE | 7 Oct 2026. DG127 custom footprint; chassis network left out |
| PCB placement, slots, holes | DONE | 8 Oct 2026. 96 × 66 mm, DRC clean on copper, silk tidy pending |
| Ground zones | DONE | 8 Oct 2026. Host + 4 islands, both layers, fills verified; 5 starved-thermal errors to clear in routing |
| Island routing | DONE | 8 Oct 2026. 4 islands, 32 vias, DRC clean on copper |
| Host routing | PLANNED | Plan DRC-clean on scratch copy (8 Oct 2026); apply to real board next, then silk tidy and review before fab |
| Order PCBs | TODO | JLCPCB |
| Hand-assemble the board | TODO | SOIC-8 MAX31855, SOIC-16W isolators, 0805 passives |
| Port firmware to ESP32-S3 | TODO | 3 channels, TFT pages, page button, TC4 protocol |
| Design + print enclosure | TODO | T-Display-S3 window, panel button, 4-channel board, probe entries |
| Clone repo to RPi | TODO | Old ~/artisan/ dir exists, needs proper clone |
| Sensor calibration | TODO | Ice water + boiling water tests |
| Mount probes in roaster | TODO | BT, ET and FT positions |
| First test roast | TODO | Full integration test |

---

## Financial Summary

### GPA Trading (PO P00041) - Thermocouples

| Item | Qty | Unit Price | Total | Status |
|---|-----|---|---|---|
| 35mm/2.5mm K-type probe | 2 | R370 | R740 | Delivered |
| 50mm/3.0mm K-type probe | 2 | R395 | R790 | Delivered |
| 70mm/3.0mm K-type probe | 2 | R415 | R830 | Delivered |
| 1/8" SS compression fitting | 6 | R550 | R3,300 | Delivered |
| **Subtotal** | | | **R5,660** | Nett, Ex VAT |
| **VAT (15%)** | | | **R849** | |
| **Total incl. VAT** | | | **R6,509** | |

### Redesign Components (Estimated — March 2026 plan, superseded)

DigiKey isolation parts order of 30 September 2026: placed and paid; order number and total not yet recorded here.

LilyGO T-Display-S3 ×1, AliExpress ref 3076608492140357, 30 September 2026: R344.00 + R29.98 shipping = R373.98, paid by card.

Panel buttons ×10, AliExpress ref 3076815630860357, 2 October 2026: R110.00 goods, R329.00 total, paid by card.

| Item | Qty | Est. Cost | Source | Notes |
|---|-----|---|---|---|
| MAX31855KASA+ IC | 5 | ~R900 | DigiKey ZA | 2/board × 2 boards + spare |
| ESP32-WROOM-32 USB-C (KS5019) | 1 | R238.20 | Mantech | Dev board for prototyping |
| Keyestudio 20×4 I2C LCD (MD0074) | 1 | R184.47 | Mantech | HD44780 + PCF8574 backpack |
| BSS138 N-MOSFET (SOT-23) | 4 | ~R4 | DigiKey | I2C level shifting (3.3V↔5V) |
| 10nF ceramic caps | 5 | ~R10 | DigiKey | Thermocouple input filter |
| 2-pin screw terminals | 6 | ~R50 | DigiKey | Thermocouple connections |
| Custom PCB | 5 | ~R80-100 | JLCPCB | Bundle with Fairfield order |
| **Estimated Total** | | **~R1,470-1,510** | | |

---

## Key Decisions Made

1. Custom K-type probes from GPA Trading instead of off-the-shelf Olimex (better specs, compression fittings, food-grade 316L SS)
2. TC4 protocol for Artisan integration (command/response, not continuous output)
3. **2-channel system** (revised from 3): BT + ET via shared SPI bus with individual CS lines
4. **Arduino Nano** (revised from UNO R3) — smaller footprint, USB-C
5. Bare tinned wire termination (direct to MAX31855 screw terminals, no connectors)
6. 6 probes ordered (2 of each size) for positioning flexibility and spares
7. USB power from RPi sufficient (~48mA total), no barrel jack needed
8. 100nF ceramic decoupling caps on each MAX31855 VCC/GND
9. 50×70mm veroboard selected (fits enclosure 61×80×23mm better than 60×40mm)
10. Thermocouple assignment: 35mm/2.5mm for BT, 50mm/3.0mm for ET
11. **ESP32-WROOM-32E** replaces Arduino Nano — 3.3V native, WiFi, more GPIO/RAM
12. **Genuine MAX31855KASA+** on custom PCB — knockoff modules unreliable (one smoked)
13. ~~**2.42" OLED** — Adafruit 2719 (SSD1305)~~ **SUPERSEDED** by decision 18
14. **Custom PCB** instead of veroboard — ESP32 + MAX31855 ICs directly on board
15. **Separate PCB** from Fairfield project — different purpose, only 2 boards needed
16. **0805 for all SMD passives** — optimal for hand soldering, matches Fairfield order
17. **5mm pitch screw terminals** for thermocouple connections — easier hand assembly than 3.5mm
18. **20×4 I2C LCD** — Keyestudio MD0074 (HD44780 + PCF8574) replaces OLED — no driver issues, no burn-in, better readability, cheaper
19. **BSS138 level shifters** for 3.3V ESP32 ↔ 5V LCD I2C on custom PCB (direct connection OK for prototype)
20. **MAX31855 breakout board first** — validate thermocouples with dev board before designing full system PCB
21. **Per-breakout galvanic isolation (MD-TC-BRK v1.1)** — probes are grounded-junction; isolated DC-DC + digital isolator on each breakout (22 April 2026)
22. **3 channels again** (BT, ET, FT) — one isolated breakout per probe (April 2026, supersedes decision 3)
23. **LilyGO T-Display-S3** as controller + display — supersedes decisions 4, 11, 14, 18, 19 (30 September 2026)
24. **Single custom 3D-printed enclosure** for T-Display-S3 + thermocouple board, designed and printed in-house (30 September 2026)
25. **One 4-channel thermocouple board** (3 fitted) instead of three breakouts, each channel on its own isolated island — supersedes the separate-breakout part of decision 21 (30 September 2026)
26. **Isolation parts:** ISO7731DWR isolator, Recom RFB-0505S DC-DC, SN74AHC125 MISO buffer, tantalum output capacitor on the NCP1117 (30 September 2026)

---

## Contact Log

| Date | Type | Summary |
|---|---|---|
| 2026-01-12 | Email | Sent quote request to Sam Hattingh (GPA Trading) for 6 custom K-type probes |
| 2026-01-23 | Email | Sam quoted prices. Jason accepted, mentioned sending full BOM with PO |
| 2026-02-02 | Email | Sent PO P00041 for thermocouples. Quenton needs them urgently |
| 2026-02-02 | Email | Sam confirmed order |
| 2026-02-09 | Email | Jason reminded Sam about invoice + banking details |
| 2026-02-09 | Email | Sam said he'll invoice once goods arrive |
| 2026-02-23 | Email | Jason sent waybill GTRCLK, Courier Guy collecting 24 Feb |
| 2026-02-24 | Email | Sam confirmed courier collected, sent invoice (attached) |
| 2026-02-24 | Email | Jason sent proof of payment |
| 2026-03-04 | Email | Jason sent RFQ for remaining BOM items |
| 2026-03-13 | Email | Sam and Jason agreed remaining BOM not worth supplying via GPA |

---

## Files Reference

- `README.md` - Project overview
- `RESUME.md` - Quick resume context
- `CLAUDE.md` - AI assistant instructions
- `correspondence/` - Supplier correspondence
- `docs/` - Technical documentation
- `kicad/` - KiCad schematic project + generator script
- `3d-prints/` - 3D printable parts (OLED bezel + Printables mounting frame)
- `FreeCad/` - FreeCAD bezel front + back piece projects
- `fritzing/` - Fritzing breadboard layout + imported parts (.fzpz)

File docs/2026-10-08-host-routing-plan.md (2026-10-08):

# Host-Side Routing Plan — 4-Channel TC Board

Written 8 October 2026 (layout session 4). Generated and DRC-checked by `kicad/tc-board-4ch/host-routing.py`, which applies the part moves and all tracks/vias to a scratch copy of the board and runs `kicad-cli pcb drc --refill-zones`. Result on the scratch copy: 0 clearance / shorting / starved-thermal errors, 0 unconnected items (was 37). Only silk and library warnings remain.

## Why five parts move

- **U1 (SN74AHC125)** sat at x 60–68 directly above C105, so the drops from its bottom pin row had nowhere to go. It moves east to the empty strip between the channel 1 DC-DC and J1, where every pin column is clear above and below.
- **C3** is U1's 3V3 decoupling and follows it.
- **C1, C2** (5V input caps) sat in the only corridor between the bus lanes and channel 2's isolator pins. They move onto the +5V bus between the DC-DC modules, each with its own via.
- **J2** (button header) moves up 1.5 mm so the MISO4 lane can pass under it.

| Ref | Old (x, y, rot) | New (x, y, rot) |
|-----|---|---|
| U1 | 64, 54.7, 90 | **77.5, 54.7, 90** |
| C3 | 58, 54.7, 90 | **71.7, 54.7, 90** |
| C1 | 87, 56.5, 0 | **96.3, 62.5, -90** |
| C2 | 90.5, 56.5, 0 | **118.5, 62.5, -90** |
| J2 | 112, 54, 0 | **112, 52.5, 0** |

Move these first (select part → E → Position). Rotation -90 puts pin 1 of C1/C2 at the top (y 61.55).

## Scheme

Short verticals on F.Cu from each pad to a via; one horizontal lane per net on B.Cu. All tracks 0.25 mm, vias 0.6/0.3 mm. Lanes are 0.63 mm apart so a via on any lane clears its neighbours by 0.205 mm.

| Lane y (B.Cu) | Net | Span x |
|---|---|---|
| 53.75 | MISO4 | 76.23 → 125.365 |
| 54.38 | CS3 | 78.77 → 105.2 |
| 55.01 | MISO3 | 80.04 → 103.365 |
| 55.64 | CS4 | 74.96 → 104.32 |
| 56.27 | +3V3 | 64.75 → 130.75 |
| 56.90 | SCK | 61.905 → 127.905 |
| 57.53 | MISO | 82.3 → 94.16 |
| 58.40 | CS1, then CS4 east leg | 60.635 → 96.7, then 104.32 → 126.635 |
| 59.05 | MISO1 west, CS2 east | 59.365 → 74.96, then 77.5 → 99.24 |
| 59.70 | MISO2 | 78.77 → 81.365 |
| 60.40 | +5V | 71.5 → 137.5 |

U1 after the move: bottom row (pins 1–7) at y 57.175, top row (pins 8–14) at y 52.225, columns x = 73.69, 74.96, 76.23, 77.5, 78.77, 80.04, 81.31. Top-row pins drop a short stub *down* under the body to a via on their lane; bottom-row pins drop *below* the body. MISO (pins 3, 6, 8, 11) is joined by an F.Cu bar at y 55.85 under the body that exits east at x 82.3. +5V reaches each DC-DC pin 1 by a short B.Cu stub straight up from the pin (no via, the pin is through-hole). GND needs only two kinds of tie: U_02 pin 2 to C_05 pin 2 on each channel, and a stub down from U1 pin 7, which clears the starved-thermal warnings.

## Step list, one net at a time

Coordinates are (x, y) in mm. Draw each track on the layer named, then DRC after each net.

### +3V3

1. F.Cu track (73.69, 52.225) → (73.69, 55.3)
2. F.Cu track (73.69, 55.3) → (71.7, 55.65)
3. F.Cu track (71.7, 55.65) → (70.6, 56.27)
4. Via at (70.6, 56.27)
5. B.Cu track (64.75, 56.27) → (130.75, 56.27)
6. Via at (64.75, 56.27)
7. F.Cu track (64.75, 56.27) → (64.75, 59.5)
8. F.Cu track (64.75, 59.5) → (64.445, 61.85)
9. Via at (86.75, 56.27)
10. F.Cu track (86.75, 56.27) → (86.75, 59.5)
11. F.Cu track (86.75, 59.5) → (86.445, 61.85)
12. Via at (108.75, 56.27)
13. F.Cu track (108.75, 56.27) → (108.75, 59.5)
14. F.Cu track (108.75, 59.5) → (108.445, 61.85)
15. Via at (130.75, 56.27)
16. F.Cu track (130.75, 56.27) → (130.75, 59.5)
17. F.Cu track (130.75, 59.5) → (130.445, 61.85)
18. F.Cu track (89.08, 52.5) → (89.08, 56.27)
19. Via at (89.08, 56.27)

### /SCK

1. B.Cu track (61.905, 56.9) → (127.905, 56.9)
2. Via at (61.905, 56.9)
3. F.Cu track (61.905, 56.9) → (61.905, 61.85)
4. Via at (83.905, 56.9)
5. F.Cu track (83.905, 56.9) → (83.905, 61.85)
6. Via at (105.905, 56.9)
7. F.Cu track (105.905, 56.9) → (105.905, 61.85)
8. Via at (127.905, 56.9)
9. F.Cu track (127.905, 56.9) → (127.905, 61.85)
10. F.Cu track (91.62, 52.5) → (91.62, 56.9)
11. Via at (91.62, 56.9)

### /MISO

1. F.Cu track (76.23, 57.175) → (76.23, 55.85)
2. F.Cu track (76.23, 55.85) → (82.3, 55.85)
3. F.Cu track (82.3, 55.85) → (82.3, 52.225)
4. F.Cu track (82.3, 52.225) → (81.31, 52.225)
5. F.Cu track (80.04, 57.175) → (80.04, 55.85)
6. F.Cu track (77.5, 52.225) → (77.5, 55.85)
7. F.Cu track (82.3, 55.85) → (82.3, 57.53)
8. Via at (82.3, 57.53)
9. B.Cu track (82.3, 57.53) → (94.16, 57.53)
10. F.Cu track (94.16, 52.5) → (94.16, 57.53)
11. Via at (94.16, 57.53)

### /CS1

1. F.Cu track (73.69, 57.175) → (73.69, 58.4)
2. Via at (73.69, 58.4)
3. B.Cu track (60.635, 58.4) → (96.7, 58.4)
4. Via at (60.635, 58.4)
5. F.Cu track (60.635, 58.4) → (60.635, 61.85)
6. F.Cu track (96.7, 52.5) → (96.7, 58.4)
7. Via at (96.7, 58.4)

### /MISO1

1. F.Cu track (74.96, 57.175) → (74.96, 59.05)
2. Via at (74.96, 59.05)
3. B.Cu track (59.365, 59.05) → (74.96, 59.05)
4. Via at (59.365, 59.05)
5. F.Cu track (59.365, 59.05) → (59.365, 61.85)

### /CS2

1. F.Cu track (77.5, 57.175) → (77.5, 59.05)
2. Via at (77.5, 59.05)
3. B.Cu track (77.5, 59.05) → (99.24, 59.05)
4. Via at (82.635, 59.05)
5. F.Cu track (82.635, 59.05) → (82.635, 61.85)
6. F.Cu track (99.24, 52.5) → (99.24, 59.05)
7. Via at (99.24, 59.05)

### /MISO2

1. F.Cu track (78.77, 57.175) → (78.77, 59.7)
2. Via at (78.77, 59.7)
3. B.Cu track (78.77, 59.7) → (81.365, 59.7)
4. Via at (81.365, 59.7)
5. F.Cu track (81.365, 59.7) → (81.365, 61.85)

### /MISO4

1. F.Cu track (76.23, 52.225) → (76.23, 53.75)
2. Via at (76.23, 53.75)
3. B.Cu track (76.23, 53.75) → (125.365, 53.75)
4. Via at (125.365, 53.75)
5. F.Cu track (125.365, 53.75) → (125.365, 61.85)

### /CS3

1. F.Cu track (78.77, 52.225) → (78.77, 54.38)
2. Via at (78.77, 54.38)
3. B.Cu track (78.77, 54.38) → (105.2, 54.38)
4. F.Cu track (101.78, 52.5) → (101.78, 54.38)
5. Via at (101.78, 54.38)
6. Via at (105.2, 54.38)
7. F.Cu track (105.2, 54.38) → (105.2, 60.3)
8. F.Cu track (105.2, 60.3) → (104.635, 60.865)
9. F.Cu track (104.635, 60.865) → (104.635, 61.85)

### /MISO3

1. F.Cu track (80.04, 52.225) → (80.04, 55.01)
2. Via at (80.04, 55.01)
3. B.Cu track (80.04, 55.01) → (103.365, 55.01)
4. Via at (103.365, 55.01)
5. F.Cu track (103.365, 55.01) → (103.365, 61.85)

### /CS4

1. F.Cu track (74.96, 52.225) → (74.96, 55.64)
2. Via at (74.96, 55.64)
3. B.Cu track (74.96, 55.64) → (104.32, 55.64)
4. F.Cu track (104.32, 52.5) → (104.32, 58.4)
5. Via at (104.32, 55.64)
6. Via at (104.32, 58.4)
7. B.Cu track (104.32, 58.4) → (126.635, 58.4)
8. Via at (126.635, 58.4)
9. F.Cu track (126.635, 58.4) → (126.635, 61.85)

### +5V

1. B.Cu track (71.5, 60.4) → (137.5, 60.4)
2. B.Cu track (71.5, 61.42) → (71.5, 60.4)
3. B.Cu track (93.5, 61.42) → (93.5, 60.4)
4. B.Cu track (115.5, 61.42) → (115.5, 60.4)
5. B.Cu track (137.5, 61.42) → (137.5, 60.4)
6. F.Cu track (86.54, 52.5) → (86.54, 55.3)
7. F.Cu track (86.54, 55.3) → (87.85, 55.3)
8. F.Cu track (87.85, 55.3) → (87.85, 60.4)
9. Via at (87.85, 60.4)
10. Via at (96.3, 60.4)
11. F.Cu track (96.3, 60.4) → (96.3, 61.55)
12. Via at (118.5, 60.4)
13. F.Cu track (118.5, 60.4) → (118.5, 61.55)

### /BTN

1. F.Cu track (106.86, 52.5) → (112, 52.5)

### GND

1. F.Cu track (81.31, 57.175) → (81.31, 58.7)
2. F.Cu track (63.175, 61.85) → (62.85, 59.5)
3. F.Cu track (85.175, 61.85) → (84.85, 59.5)
4. F.Cu track (107.175, 61.85) → (106.85, 59.5)
5. F.Cu track (129.175, 61.85) → (128.85, 59.5)

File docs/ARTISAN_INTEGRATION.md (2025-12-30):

# Artisan Integration Guide - 3-Channel Setup

How to configure Artisan coffee roasting software for the Milk Depot 3-channel thermocouple system.

## System Overview

```
┌─────────────────┐     USB Serial      ┌──────────────────┐
│   Arduino UNO   │◄──────────────────►│   Raspberry Pi   │
│                 │     115200 baud     │                  │
│  3x MAX31855    │                     │     Artisan      │
│  thermocouples  │                     │     v3.4.0       │
└─────────────────┘                     └──────────────────┘

Temperature Channels:
  Channel 1 (ET) ─── Exhaust Temperature
  Channel 2 (BT) ─── Bean Temperature
  Channel 3 (FT) ─── Flame Temperature
```

## Quick Setup (ArduinoTC4)

This is the recommended configuration using the TC4 protocol.

### Step 1: Verify Arduino Connection

```bash
# Check Arduino is connected
ls -la /dev/ttyACM*

# Test serial communication
python3 test_serial.py
```

### Step 2: Configure Primary Device

1. **Launch Artisan**: `artisan`

2. **Open Device Configuration**:
   - Menu: **Config** → **Device**

3. **Set Primary Device**:
   - Device: **ArduinoTC4**
   - Port: `/dev/ttyACM0`
   - Baud Rate: **115200**

4. **Click OK** to save

### Step 3: Add Extra Device for Flame Temperature

1. **Open Device Configuration**:
   - Menu: **Config** → **Device**

2. **Go to Extra Devices Tab**

3. **Click Add (+)**:
   - Device: **ArduinoTC4_34**
   - Leave other settings default

4. **Click OK** to save

### Step 4: Configure Curve Labels (Optional)

1. **Menu**: **Config** → **Curves**

2. **Rename curves for clarity**:
   - Extra 1: "FT" or "Flame"
   - Extra 2: (unused, can hide)

3. **Adjust colors** if desired:
   - ET: Blue
   - BT: Red/Brown
   - FT: Orange

### Step 5: Start Monitoring

1. **Click the ON button** (green button in toolbar)
2. You should see three temperature curves:
   - ET (Channel 1) - Exhaust
   - BT (Channel 2) - Bean
   - FT (Channel 3) - Flame

## Alternative: External Program Method

If you prefer continuous output (using `temp_monitor` firmware):

### Step 1: Create Parser Script

The Arduino outputs: `ET:xxx.x,BT:xxx.x,FT:xxx.x`

Artisan External Program expects: `temp1,temp2,temp3,...`

Create `/home/jason/artisan/artisan_3ch_read.py`:

```python
#!/usr/bin/env python3
"""
Parse 3-channel Arduino output for Artisan External Program
"""
import serial
import sys

PORT = '/dev/ttyACM0'
BAUD = 115200

try:
    ser = serial.Serial(PORT, BAUD, timeout=2)

    # Read lines until we get valid data
    for _ in range(5):
        line = ser.readline().decode('utf-8', errors='replace').strip()

        # Skip comments
        if line.startswith('#') or not line:
            continue

        # Parse: ET:xx.x,BT:xx.x,FT:xx.x
        if 'ET:' in line and 'BT:' in line and 'FT:' in line:
            parts = line.split(',')
            et = parts[0].split(':')[1]
            bt = parts[1].split(':')[1]
            ft = parts[2].split(':')[1]

            # Output for Artisan: ET,BT,extra1
            print(f"{et},{bt},{ft}")
            break
    else:
        print("0,0,0")

    ser.close()

except Exception as e:
    print("0,0,0")
    sys.exit(0)
```

Make it executable:
```bash
chmod +x /home/jason/artisan/artisan_3ch_read.py
```

### Step 2: Configure Artisan

1. **Config** → **Device**
2. Device: **External Program**
3. Program: `/usr/bin/python3 /home/jason/artisan/artisan_3ch_read.py`
4. **OK**

## Channel Mapping Reference

| Artisan Device | Channels Provided | Notes |
|---|---|---|
| ArduinoTC4 | ET (Ch1), BT (Ch2) | Primary device |
| ArduinoTC4_34 | Extra1 (Ch3), Extra2 (Ch4) | Extra device for additional channels |
| ArduinoTC4_56 | Heater duty, Fan duty | For output control logging |
| ArduinoTC4_78 | PID SV, Internal temp | For PID control logging |

## Troubleshooting

### No Connection / "Not Connected"

1. **Verify port**:
   ```bash
   ls /dev/ttyACM*
   # If not found, try:
   ls /dev/ttyUSB*
   ```

2. **Check permissions**:
   ```bash
   groups  # Should include 'dialout'
   ```

3. **Verify Arduino is responding**:
   ```bash
   # Open serial monitor
   screen /dev/ttyACM0 115200
   # Type: READ
   # Should see: 25.00,xxx.xx,xxx.xx,xxx.xx,0.00
   # Exit with Ctrl-A, K, Y
   ```

### Temperatures Not Updating

1. **Check sampling**:
   - Config → Device → Sampling should be 1.0s

2. **Verify data format**:
   ```bash
   python3 test_serial.py
   ```

3. **Check Artisan messages**:
   - Help → Messages
   - Look for error messages

### Extra Device Not Showing

1. Ensure **ArduinoTC4_34** is added in Extra Devices tab
2. Check Config → Curves to ensure Extra 1 curve is enabled/visible
3. Restart Artisan after adding extra device

### Flame Temperature (FT) Reads Zero

1. Verify Channel 3 is connected in firmware
2. Check MAX31855 #3 wiring (CS → D8)
3. Test thermocouple with multimeter (should show ~0-40mV at room temp)

## Curve Display Configuration

### Recommended Setup

1. **Config** → **Curves**

2. **Labels**:
   | Curve | Label | Color |
   |-------|-------|-------|
   | ET | "Exhaust" | Blue (#0000FF) |
   | BT | "Bean" | Brown (#8B4513) |
   | Extra 1 | "Flame" | Orange (#FF8C00) |

3. **Rate of Rise (RoR)**:
   - Enable for BT (most useful for roasting)
   - Optionally enable for ET

4. **Hide Unused**:
   - Extra 2 (Channel 4) can be hidden

## Testing Without Roasting

### Simulate Temperature Ramp

Use this Python script to simulate a roast:

```python
#!/usr/bin/env python3
"""Simulate a coffee roast temperature profile"""
import time
import sys

# Starting temps (room temperature)
et = 25.0
bt = 25.0
ft = 150.0  # Burner on

print("# Simulated roast starting...", flush=True)

try:
    while bt < 220:  # End at typical dark roast temp
        # Simulate temperature rise
        et += 0.8
        bt += 0.5
        ft = 350 + (50 * (0.5 - (time.time() % 1)))  # Fluctuating flame

        # Simulate first crack plateau around 195-200°C
        if 195 <= bt <= 205:
            bt += 0.2  # Slower rise during crack

        print(f"ET:{et:.1f},BT:{bt:.1f},FT:{ft:.1f}", flush=True)
        time.sleep(1)

    print("# Roast complete", flush=True)

except KeyboardInterrupt:
    sys.exit(0)
```

Save as `simulate_roast.py` and run to generate test data.

## Recording a Roast

### Standard Workflow

1. **Before roasting**:
   - Click **ON** to start monitoring
   - Verify all three curves are updating
   - Preheat roaster to target charge temperature

2. **During roast**:
   - Click **CHARGE** when beans enter drum
   - Mark **DRY END** (~160°C, color change)
   - Mark **FCs** (First Crack Start, ~196°C)
   - Mark **FCe** (First Crack End)
   - Mark **SCs** if going darker
   - Click **DROP** when beans exit

3. **After roast**:
   - Click **OFF** to stop recording
   - File → Save to store profile

### Keyboard Shortcuts

| Key | Action |
|-----|---|
| Space | Start/Stop recording |
| C | Charge |
| D | Drop |
| 1 | First Crack Start |
| 2 | First Crack End |
| 3 | Second Crack Start |

## Advanced: PID Control (Future)

If you add heater/fan control via relays:

1. Wire relay control to Arduino digital outputs
2. Update firmware to handle `OT1` and `OT2` commands
3. Configure Artisan PID with appropriate tuning
4. Enable ArduinoTC4_56 extra device for duty logging

## Resources

- [Artisan Documentation](https://artisan-scope.org/docs/)
- [Artisan Arduino/TC4 Setup](https://artisan-scope.org/devices/arduino/)
- [TC4 Protocol Reference](https://github.com/greencardigan/TC4-shield)
- [Home Roasters Forum](https://homeroasters.org)

---

**Last Updated**: 2024-12-30

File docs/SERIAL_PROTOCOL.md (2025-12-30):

# Serial Communication Protocol

Documentation for serial communication between Arduino and Artisan software.

## Overview

The Arduino reads 3 K-type thermocouples via MAX31855 amplifiers and communicates with Artisan roasting software on Raspberry Pi over USB serial.

**Temperature Channels:**
- **ET (Channel 1)**: Exhaust/Environment Temperature
- **BT (Channel 2)**: Bean Temperature
- **FT (Channel 3)**: Flame/Burner Temperature

## Connection Details

### Physical Connection
- **Interface**: USB Serial (CDC ACM)
- **Cable**: USB Type-B to USB Type-A
- **Device**: Appears as `/dev/ttyACM0` or `/dev/ttyUSB0` on Raspberry Pi

### Serial Parameters
- **Baud Rate**: 115200 bps
- **Data Bits**: 8
- **Parity**: None
- **Stop Bits**: 1
- **Flow Control**: None
- **Line Ending**: LF (`\n`)

---

## Protocol Options

### Option 1: TC4 Protocol (Recommended)

**Firmware**: `tc4_emulator`
**Artisan Device**: ArduinoTC4 + ArduinoTC4_34 (for channel 3)

This is a **command/response** protocol. Artisan sends commands, Arduino responds.

#### READ Command

```
Artisan sends:  READ\n
Arduino sends:  25.00,180.50,195.20,350.00,0.00\n
```

**Response format**: `ambient,chan1,chan2,chan3,chan4`

| Field | Description | Example |
|---|---|---|
| ambient | Ambient/reference temperature | 25.00 |
| chan1 | ET (Exhaust Temperature) | 180.50 |
| chan2 | BT (Bean Temperature) | 195.20 |
| chan3 | FT (Flame Temperature) | 350.00 |
| chan4 | Unused | 0.00 |

#### Other Commands

| Command | Description | Response |
|---|---|---|
| `READ` | Request temperature data | `ambient,c1,c2,c3,c4` |
| `CHAN;ijkl` | Set channel mapping | `# CHAN: acknowledged` |
| `UNITS;C` or `UNITS;F` | Set temperature units | `# Units: Celsius` |
| `FILT;ijkl` | Set filter values | `# FILT: acknowledged` |
| `OT1;nnn` | Heater output (0-100%) | (silent) |
| `OT2;nnn` | Fan output (0-100%) | (silent) |
| `PID;...` | PID control commands | `# PID: acknowledged` |

#### Comment Lines

Lines starting with `#` are comments (ignored by Artisan):

```
# Milk Depot Coffee Roaster
# TC4 Emulator - 3 Channel
# Channels: ET, BT, FT
# Baud: 115200
```

---

### Option 2: Continuous Output Protocol

**Firmware**: `temp_monitor`
**Artisan Device**: External Program

Arduino sends data continuously every 1000ms without commands.

#### Data Format

```
ET:xxx.x,BT:xxx.x,FT:xxx.x\n
```

**Example:**
```
ET:180.5,BT:195.2,FT:350.0
ET:181.2,BT:196.1,FT:352.3
ET:182.0,BT:197.0,FT:348.5
```

#### Fields
- `ET`: Exhaust Temperature (°C, 1 decimal)
- `BT`: Bean Temperature (°C, 1 decimal)
- `FT`: Flame Temperature (°C, 1 decimal)

---

## Data Flow Diagrams

### TC4 Protocol (Command/Response)

```
┌──────────────┐                      ┌──────────────┐
│   Artisan    │                      │   Arduino    │
│  (Raspberry  │                      │     UNO      │
│     Pi)      │                      │              │
└──────┬───────┘                      └──────┬───────┘
       │                                     │
       │  ────── READ\n ──────────────────>  │
       │                                     │
       │  <──── 25.00,180.5,195.2,350.0,0.00 │
       │                                     │
       │           (1 second later)          │
       │                                     │
       │  ────── READ\n ──────────────────>  │
       │                                     │
       │  <──── 25.00,181.2,196.1,352.3,0.00 │
       │                                     │
```

### Continuous Output Protocol

```
┌──────────────┐                      ┌──────────────┐
│   Artisan    │                      │   Arduino    │
│  (Raspberry  │                      │     UNO      │
│     Pi)      │                      │              │
└──────┬───────┘                      └──────┬───────┘
       │                                     │
       │  <──── ET:180.5,BT:195.2,FT:350.0   │
       │                                     │
       │           (1 second later)          │
       │                                     │
       │  <──── ET:181.2,BT:196.1,FT:352.3   │
       │                                     │
       │           (1 second later)          │
       │                                     │
       │  <──── ET:182.0,BT:197.0,FT:348.5   │
       │                                     │
```

---

## Artisan Configuration

### For TC4 Protocol

1. **Config** → **Device**
2. Device: **ArduinoTC4**
3. Port: `/dev/ttyACM0`
4. Baud: **115200**

5. **Config** → **Device** → **Extra Devices**
6. Add: **ArduinoTC4_34** (for Flame Temperature on channel 3)

### For Continuous Output

1. **Config** → **Device**
2. Device: **External Program**
3. Program: `/usr/bin/python3 /path/to/artisan_3ch_read.py`

Parser script example:
```python
#!/usr/bin/env python3
import serial
ser = serial.Serial('/dev/ttyACM0', 115200, timeout=2)
for _ in range(5):
    line = ser.readline().decode().strip()
    if 'ET:' in line and 'BT:' in line:
        parts = line.split(',')
        et = parts[0].split(':')[1]
        bt = parts[1].split(':')[1]
        ft = parts[2].split(':')[1]
        print(f"{et},{bt},{ft}")
        break
ser.close()
```

---

## Timing

| Parameter | Value |
|---|---|
| Sample Rate | 1 Hz (1 reading/second) |
| Sample Interval | 1000 ms |
| Response Latency | < 50 ms |
| Thermocouple Read Time | ~100 ms per channel |

---

## Error Handling

### Thermocouple Errors

When MAX31855 reports an error (open circuit, short, etc.):
- Arduino returns last good reading
- Prevents graph spikes in Artisan
- Error flag set internally (visible on OLED if enabled)

### Connection Loss

If USB disconnects:
- Artisan shows "disconnected" status
- Reconnect USB cable
- Click OFF then ON in Artisan to reconnect

### Invalid Data

- Malformed lines are ignored
- Artisan continues waiting for valid data
- Check Arduino Serial Monitor for debugging

---

## Testing

### Test TC4 Protocol

```bash
# Open serial connection
screen /dev/ttyACM0 115200

# Type (then press Enter):
READ

# Expected response:
25.00,65.32,67.45,68.12,0.00

# Exit: Ctrl-A, K, Y
```

### Test Continuous Output

```bash
# Monitor serial output
python3 test_serial.py

# Expected:
# Milk Depot Coffee Roaster - 3 Channel Temperature Monitor
# Format: ET:xxx.x,BT:xxx.x,FT:xxx.x
ET:65.3,BT:67.4,FT:68.1
ET:65.5,BT:67.6,FT:68.3
```

### Test with Python

```python
#!/usr/bin/env python3
import serial
import time

ser = serial.Serial('/dev/ttyACM0', 115200, timeout=2)
time.sleep(2)  # Wait for Arduino init

# Test TC4 protocol
ser.write(b'READ\n')
response = ser.readline().decode().strip()
print(f"Response: {response}")

# Parse response
values = response.split(',')
print(f"Ambient: {values[0]}°C")
print(f"ET: {values[1]}°C")
print(f"BT: {values[2]}°C")
print(f"FT: {values[3]}°C")

ser.close()
```

---

## Troubleshooting

### No Data Received

1. Check Arduino power (LED on)
2. Verify USB: `ls -la /dev/ttyACM*`
3. Check permissions: `groups` (should include `dialout`)
4. Test raw: `cat /dev/ttyACM0`

### Garbled Data

1. Verify baud rate (115200 on both sides)
2. Check for EMI interference
3. Try different USB cable
4. Try direct USB connection (no hub)

### Slow/Delayed Readings

1. Thicker thermocouple probes = slower response
2. Check `SAMPLE_INTERVAL_MS` in firmware
3. USB hubs add latency

### Temperature Spikes

1. Check probe connections
2. Verify thermocouple polarity (red = negative for K-type)
3. Add grounding/shielding
4. Enable Artisan smoothing filter

---

## References

- [Arduino Serial Reference](https://www.arduino.cc/reference/en/language/functions/communication/serial/)
- [Artisan ArduinoTC4 Documentation](https://artisan-scope.org/devices/arduino/)
- [TC4 Protocol Reference](https://github.com/greencardigan/TC4-shield)
- [PySerial Documentation](https://pyserial.readthedocs.io/)

---

## Version History

| Version | Date | Changes |
|---|---|---|
| 2.0 | 2024-12-30 | 3-channel support, TC4 protocol, MAX31855 |
| 1.0 | 2024-11-10 | Initial 2-channel protocol |

---

**Last Updated**: 2024-12-30

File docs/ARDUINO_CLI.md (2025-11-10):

# Arduino CLI Workflow

Complete guide for using Arduino CLI to develop and upload firmware from the Raspberry Pi.

## Overview

Arduino CLI is installed locally in this project at `/home/jason/artisan/bin/arduino-cli`. This allows direct communication with the Arduino from the Raspberry Pi without needing a separate computer.

## Installation Details

- **Version**: 1.3.1
- **Location**: `/home/jason/artisan/bin/arduino-cli`
- **Config**: `~/.arduino15/arduino-cli.yaml`
- **Cores Installed**: arduino:avr@1.8.6 (for Arduino UNO R3)
- **Libraries Installed**:
  - Adafruit MAX31855 library v1.4.2
  - Adafruit BusIO v1.17.4
  - LiquidCrystal v1.0.7

## Quick Start

### 1. Detect Arduino

```bash
cd /home/jason/artisan
./scripts/detect.sh
```

This will show connected Arduino boards and serial ports.

### 2. Compile Firmware

```bash
./scripts/compile.sh
```

Or compile a specific sketch:
```bash
./scripts/compile.sh arduino-firmware/serial_test
```

### 3. Upload to Arduino

```bash
./scripts/upload.sh
```

Or specify port and sketch:
```bash
./scripts/upload.sh arduino-firmware/temp_monitor /dev/ttyACM0
```

### 4. Monitor Serial Output

```bash
./scripts/monitor.sh
```

This runs the Python serial monitor script.

## Manual Commands

If you prefer to use arduino-cli directly:

```bash
# Add to PATH first
export PATH="/home/jason/artisan/bin:$PATH"

# List connected boards
arduino-cli board list

# Compile
arduino-cli compile --fqbn arduino:avr:uno arduino-firmware/temp_monitor/

# Upload
arduino-cli upload -p /dev/ttyACM0 --fqbn arduino:avr:uno arduino-firmware/temp_monitor/

# Monitor serial
arduino-cli monitor -p /dev/ttyACM0 -c baudrate=115200
```

## Available Sketches

### 1. temp_monitor (Main Project)
**Location**: `arduino-firmware/temp_monitor/`

Production firmware for reading two temperature probes.

**Features**:
- Reads bean temperature (BT) and drum temperature (DT)
- Sends data at 115200 baud
- Format: `BT:xxx.x,DT:xxx.x`
- Supports both analog sensors and MAX31855 modules

**To Use**:
```bash
./scripts/compile.sh arduino-firmware/temp_monitor
./scripts/upload.sh arduino-firmware/temp_monitor
./scripts/monitor.sh
```

### 2. serial_test (Diagnostic)
**Location**: `arduino-firmware/serial_test/`

Simple test sketch for verifying serial communication.

**Features**:
- Sends "Hello from Arduino!" every second
- 115200 baud
- Useful for troubleshooting

**To Use**:
```bash
./scripts/compile.sh arduino-firmware/serial_test
./scripts/upload.sh arduino-firmware/serial_test
./scripts/monitor.sh
```

## Troubleshooting

### Arduino Not Detected

**Symptom**: `arduino-cli board list` shows "No boards found"

**Solutions**:
1. **Check Physical Connection**:
   ```bash
   ls -la /dev/ttyACM* /dev/ttyUSB*
   ```
   You should see `/dev/ttyACM0` or similar.

2. **Check USB Messages**:
   ```bash
   dmesg | tail -20
   ```
   Should show Arduino connection messages.

3. **Check Permissions**:
   ```bash
   groups
   ```
   You should be in the `dialout` group (already configured).

4. **Try Different USB Port/Cable**:
   - Try another USB port on the Pi
   - Try a different USB cable (must be data cable, not charge-only)

### Upload Fails - "stk500_getsync()"

**Symptom**: `stk500_getsync() attempt X of 10: not in sync`

**Causes**:
- Arduino is running a sketch that's continuously sending serial data
- Bootloader can't sync because serial port is busy
- Wrong board type selected
- Broken Arduino hardware

**Solutions**:
1. **Press Reset During Upload**:
   - Start the upload command
   - Press the Arduino reset button when you see "Uploading..."
   - This gives the bootloader a clean window to sync

2. **Kill Processes Using Serial Port**:
   ```bash
   lsof /dev/ttyACM0
   # Kill any processes shown
   ```

3. **Try Old Bootloader**:
   ```bash
   arduino-cli upload -p /dev/ttyACM0 --fqbn arduino:avr:uno:cpu=atmega328old
   ```

4. **Re-burn Bootloader** (requires ISP programmer):
   If Arduino bootloader is corrupted, you'll need an ISP programmer to restore it.

### Garbled Serial Output

**Symptom**: Serial monitor shows garbage characters like `|p��p�p�`

**Causes**:
- Baud rate mismatch
- Broken Arduino UART hardware
- Crystal oscillator issue
- Corrupted firmware

**Solutions**:
1. **Verify Baud Rate**:
   Make sure Arduino code uses `Serial.begin(115200)` and monitor uses 115200 baud.

2. **Try Different Baud Rates**:
   ```bash
   # Test common baud rates
   for baud in 9600 19200 38400 57600 115200; do
     echo "Testing $baud"
     stty -F /dev/ttyACM0 $baud raw -echo
     timeout 2 cat /dev/ttyACM0
   done
   ```

3. **Upload Simple Test Sketch**:
   ```bash
   ./scripts/compile.sh arduino-firmware/serial_test
   ./scripts/upload.sh arduino-firmware/serial_test
   ./scripts/monitor.sh
   ```
   If this also shows garbled output, it's likely hardware.

4. **Test on Different Computer**:
   Upload the same sketch using Arduino IDE on another computer to isolate the issue.

5. **Check Arduino Board**:
   - **Clone Boards**: Some Arduino clones have bad crystals or fake UART chips
   - **Damaged Board**: Physical damage to the board
   - **Bad USB-Serial Chip**: The CH340/CP2102/ATmega16U2 chip might be faulty

**Hardware Diagnosis**:
If output is garbled at ALL baud rates on BOTH simple and complex sketches:
- **Likely Cause**: Broken Arduino board (bad crystal, damaged UART, or defective USB-serial chip)
- **Solution**: Try a different Arduino board

### No Serial Output

**Symptom**: Monitor shows nothing, no data received

**Solutions**:
1. **Wait for Arduino to Boot**:
   Arduino resets when serial connection opens. Wait 2-3 seconds.

2. **Check Firmware is Uploaded**:
   ```bash
   ./scripts/detect.sh
   ```

3. **Verify TX/RX LEDs**:
   The TX/RX LEDs on Arduino should blink when sending data.

4. **Check Code**:
   Ensure `Serial.begin()` is called in `setup()`.

### Library Not Found

**Symptom**: Compilation error about missing library

**Solution**:
```bash
export PATH="/home/jason/artisan/bin:$PATH"

# Search for library
arduino-cli lib search MAX31855

# Install library
arduino-cli lib install "Adafruit MAX31855 library"
```

### Port Access Denied

**Symptom**: `Permission denied` when accessing `/dev/ttyACM0`

**Solution**:
```bash
# Check groups
groups

# If dialout is missing, add yourself
sudo usermod -a -G dialout $USER

# Log out and back in for changes to take effect
```

## Updating Arduino CLI

To update to the latest version:

```bash
cd /home/jason/artisan
curl -fsSL https://raw.githubusercontent.com/arduino/arduino-cli/master/install.sh | sh
```

## Adding More Arduino Libraries

```bash
export PATH="/home/jason/artisan/bin:$PATH"

# Search for a library
arduino-cli lib search MAX6675

# Install a library
arduino-cli lib install "MAX6675"

# List installed libraries
arduino-cli lib list
```

## Working with Multiple Arduino Boards

If you have multiple Arduinos connected:

```bash
# List all boards with their ports
arduino-cli board list

# Upload to specific port
./scripts/upload.sh arduino-firmware/temp_monitor /dev/ttyACM1
```

## Configuration

Arduino CLI config file: `~/.arduino15/arduino-cli.yaml`

View config:
```bash
export PATH="/home/jason/artisan/bin:$PATH"
arduino-cli config dump
```

## References

- [Arduino CLI Documentation](https://arduino.github.io/arduino-cli/)
- [Arduino CLI Command Reference](https://arduino.github.io/arduino-cli/commands/arduino-cli/)
- [Arduino Serial Reference](https://www.arduino.cc/reference/en/language/functions/communication/serial/)

## Known Issues

### Current Arduino Hardware Issue

**Date**: 2025-11-10

**Symptom**: Serial output is garbled at all baud rates with patterns like `|p��p�p�`

**Diagnosis**:
- Tested multiple baud rates (9600, 19200, 38400, 57600, 115200)
- Uploaded both simple and complex sketches
- Output remains garbled regardless of configuration
- Upload sometimes succeeds, sometimes fails with sync errors

**Conclusion**: Likely broken Arduino board hardware
- Possible bad crystal oscillator (causing baud rate mismatch)
- Possible damaged UART/USB-serial chip
- Or defective Arduino clone

**Recommendation**: Test with a different Arduino UNO R3 board to verify the issue is hardware-related.

**Workaround**: None - hardware replacement needed if diagnosis is confirmed.

---

**Last Updated**: 2025-11-10

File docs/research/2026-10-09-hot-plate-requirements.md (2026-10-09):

# Hot Plate Requirements for the 96 x 66 mm Roaster Board

Researched 9 October 2026. Lean pass: a few web searches plus engineering judgement. Items marked (judgement) are not directly sourced and should be checked against a specific product's datasheet.

## Board Being Assembled

- 2-layer FR4, 96 x 66 mm, large copper zones on both layers
- SOIC-8 (MAX31855), SOIC-16W (isolators, isolated DC-DC modules), 0805 passives
- A few through-hole screw terminals and headers
- Volume: one-off, 2 to 5 boards

## Method Comparison

| Method | Fit for this board | Notes |
|---|---|---|
| Hot plate | Good, if all SMD parts are on one side | Cheapest. Heats from below, so the bottom side must be empty. Through-hole parts are hand-soldered afterwards. |
| Hot air only | Workable but slow | Hard to heat a 96 x 66 mm board with big copper pours evenly. Best as a touch-up tool. |
| Reflow oven (toaster conversion or purpose-built) | Best uniformity | More cost, more setup. Overkill for 2 to 5 boards. |

Conclusion: a hot plate is sufficient for this board. SOIC-8, SOIC-16W and 0805 are all easy reflow packages with no hidden joints (no BGA, QFN or large thermal pads). Keep a hot air gun or iron as a rework tool.

## Why Ground Pours Matter on a Plate

- A solid pour facing sparse routing on the other layer gives one region far more thermal mass and a different expansion curve, which drives warpage ([bestpcbs](https://www.bestpcbs.com/blog/2026/06/board-warpage/), [venture-mfg](https://www.venture-mfg.com/why-pcbs-warp-during-reflow/), [pcbpower](https://www.pcbpower.com/blog-detail/taking-care-of-warpage-and-thermal-profile-issues-during-assembly)).
- Similar copper coverage on both sides keeps the board flatter ([pcbpower](https://www.pcbpower.com/blog-detail/taking-care-of-warpage-and-thermal-profile-issues-during-assembly)). This board has zones on both layers, which helps.
- Board edges lose heat faster than the centre, so edge parts see a lower temperature ([pcbpower](https://www.pcbpower.com/blog-detail/taking-care-of-warpage-and-thermal-profile-issues-during-assembly)). On a plate smaller than the board this gets worse.
- (judgement) On a plate, a pour-heavy board is heated from below, so the bottom copper heats first and the top-side pads under big pours lag. SOIC pins tied to ground pours (thermal reliefs help) are the likeliest cold joints. Use the soak stage and judge by the paste, not the clock.
- (judgement) A board that bows can lift off the plate and heat unevenly. A flat aluminium plate and a gentle ramp reduce this.

## Spec Table

| Spec | Minimum sensible | Preferred | Why |
|---|---|---|-----|
| Plate area | 100 x 100 mm usable | 150 x 120 mm or larger | Board is 96 x 66 mm. The plate must extend beyond all edges to avoid cool edges. |
| Max temperature | 280 C | 300 C+ | Lead-free peak 240 to 250 C at the board needs a plate set higher because of losses. |
| Control | PID, closed loop, with set-point | PID with programmable ramp/soak/peak profile | Fixed-temperature plates overshoot and lack a defined profile. |
| Heating element | Aluminium plate with embedded heater, or ceramic | Aluminium (spreads heat evenly) | PTC plates are self-limiting, often max out near 250 C or lower; check before buying. |
| Power at 230 V | 300 to 600 W | 600 to 1000 W | Needs enough power to ramp 1 to 2 C/s on a large plate. Check the 230 V version, not a 110 V one. |
| Uniformity | Within about 5 C across the usable area (judgement) | Stated in datasheet | Ask for or measure with a thermocouple. |
| Extras | Over-temperature protection | External thermocouple input | Lets you read the board, not the plate. |
| Reference product class | FNIRSI HT-P1A, 150 W mini plate ([core-electronics](https://core-electronics.com.au/fnirsi-ht-p1a-150w-mini-hot-plate-reflow-station.html)) | Larger 600 W+ units | The 150 W mini class is small for a 96 x 66 mm board. Check its plate dimensions first. |

## Solder Paste Temperatures

| Alloy | Melting | Typical peak | Time above liquidus |
|---|---|---|---|
| Sn96.5/Ag3/Cu0.5 (SAC305) | 217 to 220 C | 240 to 250 C | 45 to 90 s |
| Sn63/Pb37 | 183 C (eutectic) | 210 to 230 C | 45 to 75 s |

Sources: [JLCPCB solder guide](https://jlcpcb.com/blog/solder-melting-point-guide), [zbotic profile](https://zbotic.in/pcb-reflow-profile-temperature-curve-for-lead-free/), [IPC](https://www.ipc.org/system/files/technical_resource/E16%26S39-03.pdf).

Leaded paste is more forgiving: lower peak, lower warpage risk, and an easier first hot plate board. Lead-free needs a plate that comfortably exceeds 250 C. The choice of paste should be settled before buying the plate.

Typical profile for guidance ([zbotic](https://zbotic.in/reflow-soldering-with-hot-plate-diy-smd-assembly-guide/)):

- Preheat: ramp 1 to 2 C/s from 25 to 150 C
- Soak: 150 to 200 C for 60 to 90 s
- Reflow: above 217 C, peak 235 to 250 C for 20 to 30 s
- Cool: about 2 to 4 C/s

## Pitfalls

- **Thermal lag:** the plate surface leads the board temperature, and a thick pour-heavy board lags further. Do not trust the plate display as the board temperature.
- **Measure the board:** tape a thermocouple (K-type, which this project already has) to a pad or the board top next to a SOIC. (judgement)
- **Tombstoning of 0805:** caused by one pad wetting before the other. Mitigations: even paste volume, slow ramp, a soak stage, and heating from below only (plates already heat evenly, which helps). Avoid one pad tied to a big pour without thermal relief. (judgement)
- **Through-hole parts:** do not put on the plate. Solder the screw terminals and headers by hand afterwards.
- **Bottom-side parts:** a plate cannot reflow a populated bottom side. Keep all SMD on the top, or do the second side with hot air or an oven.
- **When to pull the board:** when the paste visibly turns shiny and flows, and the parts self-align, then hold briefly and lift. Lifting the board off the plate onto a heat-safe surface cools faster than waiting for the plate. (judgement)
- **Cool-down:** the plate stays hot for a long time. Lift the board off with tweezers or a spatula and let it cool in air, avoiding cold-metal shock. Warp risk is highest when a hot board sits on a cooling plate.
- **Flux and fumes:** ventilate. (judgement)

## Recommended Spec Sheet to Shop Against

- Aluminium plate, at least 120 x 120 mm usable (bigger than 96 x 66 mm with margin on every side)
- 230 V mains, 600 W or more
- Max temperature 300 C or better (280 C absolute minimum for lead-free)
- PID control, ideally with a programmable profile; at least accurate set-point holding
- Over-temperature cutoff
- Separate thermocouple input is a bonus; otherwise buy a K-type meter or use the existing MAX31855 hardware
- Flat surface and sturdy legs (board must sit flat)
- Budget stance: for 2 to 5 boards, a mid-range PID plate is enough. Do not pay for a reflow oven.
- Use leaded paste if it is acceptable for this one-off, otherwise lead-free with a 300 C plate.
- Also get: a hot air gun or fine-tip iron for touch-up, a stencil or syringe paste dispenser, and tweezers.

## Sources

- https://zbotic.in/reflow-soldering-with-hot-plate-diy-smd-assembly-guide/
- https://zbotic.in/pcb-hot-plate-reflow-soldering-with-pid-control/
- https://zbotic.in/pcb-reflow-profile-temperature-curve-for-lead-free/
- https://core-electronics.com.au/fnirsi-ht-p1a-150w-mini-hot-plate-reflow-station.html
- https://www.pcbpower.com/blog-detail/taking-care-of-warpage-and-thermal-profile-issues-during-assembly
- https://www.venture-mfg.com/why-pcbs-warp-during-reflow/
- https://www.bestpcbs.com/blog/2026/06/board-warpage/
- https://jlcpcb.com/blog/solder-melting-point-guide
- https://www.ipc.org/system/files/technical_resource/E16%26S39-03.pdf

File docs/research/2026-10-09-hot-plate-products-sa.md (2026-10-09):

# Hot Plate / PCB Preheater Options for South Africa

Date: 09 October 2026. Target: reflow a 96 x 66 mm 2-layer board (SOIC + 0805) from Johannesburg.

## Method and limits

Web search plus page fetches. Most SA shop sites (Communica, Mantech, Takealot) render with JavaScript and returned no product data, so their stock is **unverified**, not "none". Only DIY Electronics surfaced via search. Import prices below are marked "est." where I could not load a live AliExpress/Banggood page. Exchange rate assumed about R17.50/US$ (not checked live). Verify before ordering.

## Key finding: plate size decides it

The board is 96 x 66 mm (diagonal about 116 mm). Plates must exceed about 100 x 70 mm to heat it evenly.

- Miniware MHP30 plate is 30 x 30 mm: **too small**.
- Miniware MHP50 / FNIRSI HT-P1A plate is 50 x 50 mm: **too small** for the whole board (would only heat part; large gradients, warping risk).
- A 100 x 100 mm plate is the practical minimum; 200 x 200 mm is comfortable and gives even heat.

## Comparison table

| Product | Plate size | Max temp | Control | Price ZAR | Source | Lead time | URL |
|---|---|---|---|---|---|---|---|
| Miniware MHP30 PD | 30 x 30 mm | 300-350 C | Preset temps, USB-C PD, 60 W | R2,207.00 | DIY Electronics (SA) | local, days | https://www.diyelectronics.co.za/store/soldering-irons/3887-miniware-mhp30-pd-mini-hot-plate-preheater.html |
| Miniware MHP50-A5 aluminium | 50 x 50 mm | 350 C | PID, USB-C PD / DC | R1,699.15 (sale from R1,999.00) | DIY Electronics (SA) | local, days | https://www.diyelectronics.co.za/store/solder-accessories/5243-miniware-mhp50-a5-aluminium-hot-plate-preheater.html |
| Miniware MHP50-B5 brass | 50 x 50 mm | 350 C | PID, USB-C PD / DC | R2,399.95 | DIY Electronics (SA) | local, days | https://www.diyelectronics.co.za/store/soldering-irons/5244-miniware-mhp50-b5-brass-hot-plate-preheater.html |
| FNIRSI HT-P1A | 50 x 50 mm | 350 C | PID +/-3 C, 100-150 W, USB-C PD/DC | not found in SA (about A$154 in AU) | import only | 3-5 wk | https://core-electronics.com.au/fnirsi-ht-p1a-150w-mini-hot-plate-reflow-station.html |
| UYUE 946-1010 | 100 x 100 mm (per model name; size unverified) | about 350 C | Digital, thermostat | est. R1,300-1,900 landed | AliExpress / eBay | 3-5 wk | https://probots.co.in/uyue-946-1010-preheat-desoldering-rework-station-aluminium-heating-plate-220v-us-plug-bga-smd.html (spec page) |
| UYUE 946C | 200 x 200 mm, 15 mm Al plate | 350 C | Digital LED, +/-1.5 C, 800 W, 220 V | est. R2,200-2,900 landed (eBay US$87-124 + shipping + VAT) | AliExpress / eBay | 3-5 wk | https://probots.co.in/946c-800w-electronic-hot-plate-preheating-station-200x200mm.html (spec page) |
| Generic 946B/T-946 Mcup | 180 x 240 mm, 800-850 W | about 350 C | Digital | est. R1,800-2,600 landed | eBay / AliExpress | 3-5 wk | https://www.ebay.de/itm/196802474458 |
| Yihua 853A (IR plate) | 120 x 120 mm | not confirmed | PID | not found in SA | import | 3-5 wk | https://probots.co.in/yihua-853a-preheat-desoldering-rework-station-ir-heating-plate-220v-us-plug-esd-bga.html |
| Hakko FR-860 / Weller WXHP120 | large | professional | professional | well over R10,000, not priced | distributors | weeks | https://valuetronics.com/apps/aeo/ai/md/default/products/fr860-02-hakko-soldering-new.md |
| Generic 100x100 / 200x200 PTC plate | 100 or 200 mm | about 200-250 C only | Fixed PTC, no control | not priced | AliExpress | 3-5 wk | n/a |

## Notes per candidate

- **MHP30 / MHP50 / FNIRSI**: well made, but plates are 30 or 50 mm. Fine for single ICs, not for this board. USB-C PD powered, so no mains-voltage concern.
- **UYUE 946 family**: mains-powered resistive plates, PID-less to simple digital thermostat. The 946C (800 W, 200 x 200) is widely used for exactly this job (Voltlog #210 review: https://www.voltlog.com/?p=978). It has no reflow profile, so you ramp by hand and watch the plate. Fine for leaded or low-temp lead-free paste with a thermocouple/IR thermometer.
- **Generic PTC plates**: cap near 200-250 C, which is marginal for lead-free paste (about 235-245 C peak). Avoid unless using leaded paste.
- **Ersa IRHP, Aixun, Controleo**: nothing SA-stocked found; Ersa/Hakko/Weller are professional pricing. Controleo is a DIY oven controller, not a plate, so it is out of scope for the budget.
- No well-reviewed 2025-2026 100 x 100+ models turned up beyond the 946 family in the searches run. Not exhaustively searched.

## South African stock

| Retailer | Result |
|---|---|
| DIY Electronics | Stocks MHP30 and MHP50 only (prices above). Free shipping over R1,250. No large plate seen. |
| Communica, Mantech, Takealot, RS ZA, Micro Robotics, Robotics.org.za, Netram, Electro Mechanica | Could not be read (JavaScript sites / error page). No hot plate found via search. Check by phone or site search: Communica sales@communicagroup.com, +27 12 657 3500. |

Local sellers on Takealot or Facebook occasionally list the 946C; worth one manual search for "946C" and "YIHUA 946".

## Import options

- **Delivery**: AliExpress Standard to SA is typically 3-5 weeks (you already see about 4 weeks). Banggood and eBay are similar; AliExpress "local warehouse" items are faster but rare for this category.
- **Landed cost**: SARS charges 15% VAT on low-value parcels since the September 2024 change, and the old under-R500 duty concession has been closed down, so expect VAT plus possibly duty on tools/electronics (source below). Budget item price + shipping, then add 15% VAT, and about 10-20% extra for duty/handling in a worst case. Courier clearing fees (DHL/Aramex) can add roughly R100-250 if a courier delivers.
- **Voltage and plug**: 946-family plates are sold as 220 V or 110/220 V. SA mains is 230 V, so 220 V is fine. Listings often say "US plug" or "EU plug": you will need an adapter or to swap the lead, and the plug is the usual trap. SA uses a type M/N plug (the 3-pin round), so buy an earthed adapter or fit a proper SA cord. Do not use a flimsy 2-pin adapter on an 800 W heater. Confirm "220 V" in the title; avoid 110 V-only units.
- **Safety**: cheap mains plates may lack an earth connection; check the plate chassis earth before use.

## Shortlist for a 96 x 66 mm board

| Tier | Pick | Why |
|---|---|---|
| Good | Generic T-946 / 946B 180 x 240 mm plate, 220 V (est. R1,800-2,600 landed) | Cheapest way to get a plate big enough; manual ramping only. |
| Better | UYUE 946C, 200 x 200 mm, 800 W, 220 V (est. R2,200-2,900 landed) | Known reviewed unit with +/-1.5 C stability and thick plate for even heat; 3-5 week wait. |
| Best | Local-first: ask Communica/Mantech for any 200 mm plate; otherwise 946C plus a K-type probe/IR thermometer for profile control | Nothing premium with profiles is SA-stocked at hobby price. Hakko FR-860 / Weller WXHP120 are the pro step-up but cost far more. |

If you must have it this week, the only in-stock SA options (MHP50) cannot cover this board in one go; a stopgap is not recommended.

## Sources

- DIY Electronics MHP30: https://www.diyelectronics.co.za/store/soldering-irons/3887-miniware-mhp30-pd-mini-hot-plate-preheater.html
- DIY Electronics MHP50-B5: https://www.diyelectronics.co.za/store/soldering-irons/5244-miniware-mhp50-b5-brass-hot-plate-preheater.html
- DIY Electronics MHP50-A5: https://www.diyelectronics.co.za/store/solder-accessories/5243-miniware-mhp50-a5-aluminium-hot-plate-preheater.html
- Probots UYUE 946C spec: https://probots.co.in/946c-800w-electronic-hot-plate-preheating-station-200x200mm.html
- Probots UYUE 946-1010: https://probots.co.in/uyue-946-1010-preheat-desoldering-rework-station-aluminium-heating-plate-220v-us-plug-bga-smd.html
- eBay 946C listings (US$87-124): https://www.ebay.de/itm/388508518093
- eBay T-946 Mcup 180x240: https://www.ebay.de/itm/196802474458
- Voltlog 946C review: https://www.voltlog.com/?p=978
- Core Electronics FNIRSI HT-P1A: https://core-electronics.com.au/fnirsi-ht-p1a-150w-mini-hot-plate-reflow-station.html
- Core Electronics MHP30: https://core-electronics.com.au/morning-tools-mini-hot-plate-preheater-mph30.html
- Evetech on 2026 low-value parcel rules: https://evezone.evetech.co.za/quick-bytes/low-value-parcel-rules-2026-changed-sa-shoppers
- Nedbank on Shein/Temu taxes: https://personal.nedbank.co.za/learn/blog/shein-temu-taxes-south-africa.html

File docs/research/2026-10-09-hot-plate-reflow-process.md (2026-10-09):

# Hot-Plate Reflow: Process and Consumables

Date: 9 October 2026. Board: 96 x 66 mm, 2-layer, SOIC-8, SOIC-16W, 0805, plus through-hole screw terminals and pin headers. One person, South Africa, 2-5 boards.

Confidence note: alloy temperatures and JLCPCB stencil facts come from the sources below. SA retail prices could not be verified from search (no Communica, Mantech or Takealot pages were returned) and must be checked by hand. Items marked "(general practice)" are standard hobbyist guidance, not tied to a fetched page.

## 1. Solder paste

| Alloy | Melts | Typical peak | Plate suitability |
|---|---|---|---|
| Sn63/Pb37 (Chip Quik SMD291AX, MG Chemicals) | 183 C | 205-215 C | Most forgiving: low peak, good wetting, wide margin below component limits |
| Sn42/Bi58 | 138 C | 165-180 C | Gentlest on the board and easiest on a plate, but joints are brittle and a mixed Bi/Pb contamination weakens joints. Not ideal for a roaster-adjacent product with vibration/heat cycling |
| SAC305 | 217-220 C | 230-250 C | Hardest on a plate: needs a hot, well-controlled plate and a tight peak window. Use only if lead-free is required |

Recommendation: Sn63/Pb37 syringe for a hobby build used by Jason (workshop use, not sold as a consumer product). If the board will be handed to a client or must be RoHS-clean, use SAC305 and expect to need a plate that reaches 250 C and an IR thermometer.

Storage and handling (general practice): keep paste in a fridge (about 2-10 C), never freezer. Let it reach room temperature unopened for 2-4 hours before use to avoid condensation. Leaded paste in a fridge lasts roughly 6-12 months; check the label. Do not return used paste to the syringe.

Syringe vs jar: syringe (15-35 g) for hand dispensing and for small runs; it keeps paste sealed and is easy to dab onto pads. Jars (250 g) suit stencil printing at volume, not 2-5 boards.

SA availability and price: not verified. RS Components ZA lists Chip Quik SMD291AX (Sn63, no-clean) in 15 g and 35 g syringes (overseas RS prices: about 12.89 GBP for 15 g, 19.23 GBP for 35 g ex VAT, so expect roughly R350-R800 in SA after import and VAT). Check Communica, Mantech, RS ZA and Takealot directly. If SA stock is poor, DigiKey ZA (already used on this project) stocks Chip Quik TS391AX (15 g) and MG Chemicals 4860P-35G.

## 2. Stencil

JLCPCB offers framed stencils (for printing machines, fixed standard sizes) and unframed ("frameless") stencils with a custom outline. Unframed starts from about US$3 and can ship in the same parcel as the PCBs if smaller than 200 x 200 mm. A 96 x 66 mm board fits easily. Order the unframed, custom-size, stainless-steel, top-side stencil, with stencil size chosen just larger than the board (for example 120 x 100 mm) to leave a margin for tape.

Jig (general practice): tape the board down on a flat surface with a few spare bare PCBs (or 1.6 mm sheet) of equal thickness on three sides, so the stencil lies flat. Align stencil apertures to pads under good light, tape one edge with Kapton to act as a hinge, drag paste with a plastic card or small metal squeegee at roughly 45 degrees in one pass, then peel straight up.

Stencil vs syringe for 2-5 boards: with SOIC-16W (1.27 mm pitch) and 0805, hand dispensing is workable but slow and uneven. A stencil at about US$3 plus shipping is cheap compared with the time and the bridging risk, so it is worth ordering with the PCBs. Because there are through-hole parts, make sure the stencil file only has SMD apertures (the default).
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

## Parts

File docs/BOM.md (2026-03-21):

# Bill of Materials (BOM)

Complete parts list for the Milk Depot Coffee Roaster temperature monitoring system.

**Revision 2.0** — ESP32 redesign with genuine MAX31855 ICs on custom PCB.

## Overview

This system uses 2 K-type thermocouples with genuine MAX31855KASA+ thermocouple-to-digital converters connected to an ESP32, which communicates with Artisan roasting software on a Raspberry Pi 4 via USB serial.

**Temperature Channels:**
- **BT (Bean Temperature)**: 35mm/2.5mm probe inside the drum, measures bean mass temperature
- **ET (Exhaust/Environment Temperature)**: 50mm/3.0mm probe in exhaust path, measures air leaving the drum

**Design Decisions:**
- ESP32-WROOM-32E replaces Arduino Nano — 3.3V native (no level shifters for MAX31855), WiFi capability, more GPIO/RAM
- Genuine MAX31855KASA+ ICs (SOIC-8) on custom PCB — knockoff breakout modules proved unreliable (one smoked on first power-up)
- 2.42" OLED (SSD1309) replaces 1.3" SH1106 — 4× screen area, same 128×64 resolution
- All SMD passives are **0805** — optimal size for hand soldering with fine-tip iron or hot air

---

## Thermocouples (Delivered)

**PO P00041 — GPA Trading (Sam Hattingh) — DELIVERED & PAID**

See [THERMOCOUPLE_SPEC.md](THERMOCOUPLE_SPEC.md) and [CUSTOM_TC_ORDER_SPEC.md](CUSTOM_TC_ORDER_SPEC.md) for detailed specifications.

| Qty | Description | Assignment | Unit Price | Total |
|-----|---|---|---|---|
| 2 | 35mm/2.5mm K-type probe, 1.5m cable, SS316L, grounded | BT (Bean Temp) | R370 | R740 |
| 2 | 50mm/3.0mm K-type probe, 1.5m cable, SS316L, grounded | ET (Exhaust Temp) | R395 | R790 |
| 2 | 70mm/3.0mm K-type probe, 1.5m cable, SS316L, grounded | Spare | R415 | R830 |
| 6 | 1/8" SS compression fitting | Panel mount | R550 | R3,300 |
| | **Subtotal (ex VAT)** | | | **R5,660** |
| | **VAT (15%)** | | | **R849** |
| | **Total incl. VAT** | | | **R6,509** |

Bare tinned wire termination — direct to screw terminals on PCB, no miniature connectors.

---

## ICs — DigiKey ZA

| Qty | MPN | Description | Package | DigiKey PN | Est. Unit | Est. Total |
|-----|-----|---|---|---|---|---|
| 5 | MAX31855KASA+ | K-type thermocouple-to-digital converter | SOIC-8 | MAX31855KASA+-ND | ~R150 | ~R750 |
| 2 | ESP32-WROOM-32E-N4 | WiFi/BT module, 4MB flash | Module | ESP32-WROOM-32E-N4CT-ND | ~R57 | ~R114 |

**MAX31855 qty 5**: 2 per board × 2 boards + 1 spare.
**ESP32 qty 2**: For custom PCB (not dev board). 1 active + 1 spare.

---

## Passive Components — DigiKey ZA (all 0805 SMD)

| Qty | MPN | Value | Specs | DigiKey PN | Purpose |
|-----|-----|---|---|---|---|
| 10 | CL21B104KBCNNNC | 100nF | X7R, 50V, ±10% | 1276-1003-1-ND | IC decoupling (VCC to GND) |
| 10 | CL21B103KBANNNC | 10nF | X7R, 50V, ±10% | 1276-1015-1-ND | MAX31855 TC input filter (T+ to T-) |
| 10 | GRM21BR61C106KE15L | 10µF | X5R, 16V, ±10% | 490-3886-1-ND | ESP32 bulk decoupling |
| 10 | RC0805FR-0710KL | 10K Ω | 1%, 1/8W | 311-10.0KCRCT-ND | I2C pull-ups, ESP32 EN/IO0 |

**Why these specific parts:**
- Samsung CL21B series (100nF, 10nF) — widely stocked, consistent quality, good price
- Murata GRM21B series (10µF) — premium MLCC, excellent DC bias characteristics
- Yageo RC0805FR — industry standard thick film resistor, 1% tolerance
- All 0805 (2.0 × 1.25mm) — one size simplifies assembly and ordering
- All passives shared with Fairfield project DigiKey order (100 qty each)

---

## Connectors — DigiKey ZA (through-hole)

| Qty | MPN | Description | Pitch | DigiKey PN | Purpose |
|-----|-----|---|---|---|---|
| 6 | 1725656 | 2-pin screw terminal | 5.0mm | 277-1247-ND | Thermocouple wire connections |
| 5 | B3F-1000 | Tactile switch, 6×6mm | - | SW400-ND | OLED page button |
| 3 | - | 4-pin 2.54mm pin header | 2.54mm | - | OLED display connector |

**Screw terminal qty 6**: 2 per board × 2 boards + 2 spares. 5mm pitch chosen for hand-assembly ease.

---

## Dev Board — Mantech (Prototyping)

| Qty | Product | Stock Code | Price (ex VAT) |
|-----|---|---|---|
| 1 | Keyestudio KS5019 ESP32-WROOM-32 USB-C 38-pin | ME106299 | R238.20 |

For prototyping before custom PCB arrives. Has USB-C, 3.3V LDO, USB-UART bridge, boot button — everything needed to test firmware and MAX31855 ICs.

---

## Display — DigiKey ZA (Adafruit)

| Qty | MPN | Description | Controller | DigiKey PN | Est. Price |
|-----|-----|---|---|---|---|
| 1 | 2719 | Adafruit 2.42" 128×64 OLED Module Kit | SSD1305 | 1528-1591-ND | ~R460-550 |

Upgrade from 1.3" SH1106. Same 128×64 resolution, ~4× screen area. Premium Adafruit quality with bezel, 4 mounting holes, and standard 2.54mm header. Uses `Adafruit_SSD1305` library (same GFX API as SSD1306, only init object changes). Adding to DigiKey order avoids a separate purchase.

---

## Prototyping Supplies

| Qty | Description | Source | Est. Price |
|-----|---|---|---|
| 5-10 | SOIC-8 to DIP adapter PCBs | AliExpress | ~R20-40 pack |
| 1 | Breadboard (if needed) | On hand | R0 |
| 1 | Jumper wire kit | On hand | R0 |

SOIC-8 adapters needed because MAX31855KASA+ cannot be breadboarded directly. Solder IC + decoupling cap to adapter, then plug into breadboard for prototype testing.

---

## Custom PCBs — JLCPCB (Future)

| Qty | Description | Est. Price |
|-----|---|---|
| 5 | MAX31855 breakout PCB (small, SOIC-8 + caps + screw terminal) | ~R40-50 |
| 5 | Main ESP32 system PCB (full integration) | ~R80-100 |

Breakout PCB ordered first for prototyping. Main PCB designed after prototype validation.

---

## Enclosure & Mounting

| Qty | Description | Supplier | Est. Price |
|-----|---|---|---|
| 1 | ABS project box (~150×100×50mm or larger) | Communica / Mantech | R80-120 |
| 1 | Cable gland PG9 (USB cable entry) | Communica / Builders | R15 |
| 4 | M3 standoffs, 10mm brass | Communica | R20 (pack) |
| 1 | Heat shrink tubing, assorted | Communica | R25 |

Enclosure may need to be larger than originally planned to accommodate 2.42" OLED (wider than 1.3").

---

## Cost Summary

| Category | Est. Cost (ZAR) | Status |
|---|---|---|
| Thermocouples + fittings (GPA Trading) | R6,509 incl VAT | **Paid** |
| MAX31855KASA+ × 5 (DigiKey) | ~R750 | Pending |
| ESP32-WROOM-32E-N4 × 2 (DigiKey) | ~R114 | Pending |
| Passive components (DigiKey) | ~R50 | Pending |
| Connectors (DigiKey) | ~R100 | Pending |
| ESP32 dev board (Mantech) | ~R274 incl VAT | Pending |
| Adafruit 2.42" OLED (DigiKey) | ~R460-550 | Pending |
| Prototyping supplies | ~R40 | Pending |
| Custom PCBs (JLCPCB) | ~R120-150 | Future |
| Enclosure & mounting | ~R140 | Future |
| **DigiKey order subtotal** | **~R1,474-1,564** | |
| **Total new components** | **~R1,830-1,960** | |
| **Project total (incl. thermocouples)** | **~R8,340-R8,470** | |

*DigiKey ZA: Free delivery on orders over R2,000. Combining with Fairfield project order to reach threshold.*
*Raspberry Pi 4 already owned, not included.*

---

## DigiKey Order Checklist

Combined order with Fairfield project for R2,000 free shipping threshold.

**Already in cart (shared with Fairfield, covers roaster needs):**
- [x] ~~MAX31855KASA+-ND × 10~~ (roaster uses 5)
- [x] ~~1965-ESP32-WROOM-32E-N4CT-ND × 13~~ (roaster uses 2)
- [x] ~~1276-1003-1-ND × 100~~ (100nF 0805, roaster uses ~10)
- [x] ~~1276-1015-1-ND × 100~~ (10nF 0805, roaster uses ~10)
- [x] ~~490-3886-1-ND × 100~~ (10µF 0805, roaster uses ~10)
- [x] ~~311-10.0KCRCT-ND × 100~~ (10K 0805, roaster uses ~10)
- [x] ~~NCP1117ST33T3GOSCT-ND × 10~~ (3.3V LDO, roaster uses ~2)
- [x] ~~1727-4043-1-ND × 20~~ (MMBT2222A, roaster uses ~4)
- [x] ~~EG2531CT-ND × 30~~ (tactile switch SMD, roaster uses ~3)

**Still need to add to cart:**
- [ ] 277-1247-ND × 6 (2-pin 5mm screw terminal, Phoenix Contact 1725656)
- [ ] 1528-1591-ND × 1 (Adafruit 2.42" OLED module 2719)

**Note**: Verify all DigiKey part numbers before ordering — prices and stock change frequently.

---

## Pin Assignment (ESP32)

Pin assignments for custom PCB (final GPIO allocation during KiCad design):

| ESP32 GPIO | Function | Connected To |
|---|---|---|
| VSPI SCK (GPIO 18) | SPI Clock | Both MAX31855 SCK (shared) |
| VSPI MISO (GPIO 19) | SPI Data | Both MAX31855 DO (shared) |
| GPIO 5 | CS_BT | MAX31855 #1 CS (Bean Temp) |
| GPIO 17 | CS_ET | MAX31855 #2 CS (Exhaust Temp) |
| GPIO 21 | I2C SDA | OLED SDA (+ 10K pull-up to 3.3V) |
| GPIO 22 | I2C SCL | OLED SCL (+ 10K pull-up to 3.3V) |
| GPIO 4 | Button | Tactile switch to GND (internal pull-up) |
| 3V3 | Power | MAX31855 VCC, OLED VCC |
| GND | Ground | All GND |

**Notes:**
- ESP32 is 3.3V native — MAX31855 operates at 3.0-3.6V, no level shifting needed
- VSPI is the default SPI bus on ESP32 (HSPI also available if needed)
- GPIO 21/22 are the default I2C pins on ESP32
- Avoid GPIO 6-11 (connected to internal flash on WROOM modules)

---

## Wiring Diagram

```
                                    +------------------+
                                    |   RASPBERRY PI   |
                                    |       USB        |
                                    +--------+---------+
                                             |
                                        USB-C Cable
                                             |
+---------------------------+       +--------+---------+
|      ENCLOSURE            |       | ESP32-WROOM-32E  |
|                           |       |                  |
|  +-----------+            |       | GPIO18 ---+----- | ---> SCK (shared)
|  | MAX31855  |            |       | GPIO19 ---+----- | ---> MISO (shared)
|  | #1 (BT)   |           |       | GPIO5  --------- | ---> CS_BT
|  | SOIC-8    |            |       | GPIO17 --------- | ---> CS_ET
|  +-----+-----+            |       | GPIO21 --------- | ---> OLED SDA
|        |                  |       | GPIO22 --------- | ---> OLED SCL
|  +-----------+            |       | GPIO4  --------- | ---> Button
|  | MAX31855  |  +------+  |       | 3V3  ----+----- | ---> VCC (shared)
|  | #2 (ET)   |  | OLED |  |       | GND  ----+----- | ---> GND (shared)
|  | SOIC-8    |  | 2.42"|  |       +------------------+
|  +-----+-----+  +------+  |
|        |                   |
+--------+-------------------+
         |
    5mm Screw Terminals
         |
   +-----+-----+  +-----+-----+
   | TC BT      |  | TC ET      |
   | 35mm/2.5mm |  | 50mm/3.0mm |
   +------------+  +------------+
   (1.5m leads to roaster)
```

---

## Supplier Quick Reference (South Africa)

| Supplier | Website | Use For |
|---|---|---|
| DigiKey ZA | digikey.co.za | ICs, passives, connectors (primary) |
| Mantech | mantech.co.za | ESP32 dev boards, modules |
| RS Components | za.rs-online.com | Industrial connectors, alternative ICs |
| Communica | communica.co.za | Enclosures, general electronics |
| JLCPCB | jlcpcb.com | Custom PCB fabrication |
| AliExpress | aliexpress.com | OLED displays, adapter boards |

---

## Version History

| Version | Date | Changes |
|---|---|---|
| 1.0 | 2024-12-30 | Initial 3-channel Arduino UNO design |
| 2.0 | 2026-03-20 | ESP32 redesign: genuine MAX31855KASA+, 0805 passives, 2.42" OLED, custom PCB |

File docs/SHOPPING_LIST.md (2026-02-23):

# Shopping List - Milk Depot Coffee Roaster

Printable shopping list for the 3-channel thermocouple temperature monitoring system.

**Date**: December 2024
**Project**: Milk Depot Coffee Roaster Temperature Monitor
**Budget Estimate**: R800 - R1,500 (depending on thermocouple source)

---

## Priority 1: Thermocouples (CRITICAL - Get These Right!)

**Required Specification:**
- K-type insertion probe (NOT surface mount)
- 3mm diameter stainless steel sheath
- 100-150mm probe length
- 1.5m cable with miniature K-type connector
- Grounded junction preferred

See [THERMOCOUPLE_SPEC.md](THERMOCOUPLE_SPEC.md) for detailed specifications.

### Option A: RS Components South Africa (Recommended)

| Qty | RS Part # | Description | Price Est. | Notes |
|-----|---|---|---|---|
| 3 | 3971264 | Type K MI Thermocouple, 150mm, 3mm dia, +1100°C | ~R400-600 ea | **Best match** - mineral insulated, flexible |

**Website**: [za.rs-online.com](https://za.rs-online.com/web/p/thermocouples/3971264)
**Phone**: 011 691 9300

**Alternative RS options:**
- 7877848: Type K MI, 1.5m length, 3mm dia (longer probe)
- 3428990: Type K Air Probe, 110mm, 4mm dia (slightly thicker)

### Option B: Custom Manufacture - Thermon South Africa

**Best for exact specifications - can make to order.**

| Contact | Details |
|---|---|
| Johannesburg | +27 11 966 9800 |
| Cape Town | +27 21 762 8995 |
| Email | salessa@energisolutionsafrica.com |
| Website | [thermon.co.za](https://www.thermon.co.za) |

**Capabilities:**
- Custom thermocouples to your spec
- Mineral insulated down to 0.5mm diameter
- "SOS" fast turnaround service
- All types: J, K, T, R, S, PT100

**Request quote using template in THERMOCOUPLE_SPEC.md**

### Option C: Custom Manufacture - Thermocouple Products (Pty) Ltd

**Local manufacturer in Edenvale (Gauteng)**

| Contact | Details |
|---|---|
| Location | Edenvale, Gauteng |
| Website | [thermocoupleproducts.co.za](https://thermocoupleproducts.co.za) |
| Specialty | Custom thermocouples for any industry |

**Request quote using template in THERMOCOUPLE_SPEC.md**

### Option D: Ready-Made (Higher Price)

| Supplier | Product | Price | Notes |
|---|---|---|---|
| Ecotao Store | Type K 150mm, 4.5mm dia | R665 | Slightly thick but available |
| Hanna SA | HI766E2 220mm, 5mm dia | R2,639 | Expensive, includes handle |

**Ecotao**: [ecotao-store.co.za](https://www.ecotao-store.co.za/shop/laboratory/thermometers/datalogging-thermometer/type-k-heavy-duty-thermocouple-150mm-length-4-5mm-diameter-350c/)

### Thermocouple Cost Estimate

| Source | Unit Price | Qty 3 Total |
|---|---|---|
| RS Components | R400-600 | R1,200-1,800 |
| Custom (Thermon) | R200-400 est. | R600-1,200 |
| Ecotao | R665 | R1,995 |

---

## Priority 2: Thermocouple Amplifiers

| Qty | Item | Description | Est. Price Each | Total |
|-----|---|---|---|---|
| 3 | MAX31855 Module | K-Type thermocouple amp, SPI interface | R50-80 | R150-240 |

**Where to buy** (check stock/prices):
- [ ] Communica: [communica.co.za](https://www.communica.co.za) (search "MAX31855")
- [ ] Micro Robotics: [robotics.org.za](https://www.robotics.org.za)
- [ ] DIY Electronics: [diyelectronics.co.za](https://www.diyelectronics.co.za)
- [ ] Netram: [netram.co.za](https://www.netram.co.za)
- [ ] AliExpress (longer shipping): search "MAX31855 module"

**Important**: Ensure modules have miniature K-type socket (yellow, flat blade style)

---

## Priority 3: Enclosure & Mounting

| Qty | Item | Description | Est. Price | Notes |
|-----|---|---|---|---|
| 1 | ABS Project Box | 150x100x50mm (approx) | R80-120 | Black or gray |
| 3 | Panel Mount K-Type Socket | Female miniature thermocouple connector | R30-50 each | Optional but recommended |
| 1 | Cable Gland PG9 | For USB cable entry | R15-25 | Or use rubber grommet |
| 1 | Pack M3 Standoffs | Brass, 10mm, for Arduino mount | R20-30 | Pack of 4+ |

**Where to buy**:
- [ ] Communica: [communica.co.za](https://www.communica.co.za)
- [ ] Mantech: [mantech.co.za](https://www.mantech.co.za)
- [ ] Builders Warehouse (cable glands)
- [ ] RS Components: [za.rs-online.com](https://za.rs-online.com) (panel mount connectors)

**Subtotal: ~R175-275**

---

## Priority 4: Wiring & Assembly

| Qty | Item | Description | Est. Price |
|-----|---|---|---|
| 1 | Jumper Wire Kit | Male-Female + Female-Female Dupont, 20cm | R30-50 |
| 1 | Perfboard 5x7cm | For mounting MAX31855 modules | R10-20 |
| 1 | Heat Shrink Kit | Assorted sizes | R20-30 |
| 1 | USB A-B Cable 2m | Arduino to Raspberry Pi | R25-40 |

**Subtotal: ~R85-140**

---

## Priority 5: Optional Extras

| Qty | Item | Description | Est. Price | Notes |
|-----|---|---|---|---|
| 1 | SSD1306 OLED | 0.96" 128x64 I2C display | R40-60 | Local temperature readout |
| 1 | Power LED + Resistor | 5mm green LED + 220Ω | R5 | Power indicator |

**Subtotal: ~R45-65**

---

## Budget Summary

| Category | Budget Option | Premium Option |
|---|---|---|
| Thermocouples (3x) | R600 (custom) | R1,800 (RS) |
| Amplifiers (3x) | R150 | R240 |
| Enclosure & Mounting | R175 | R275 |
| Wiring & Assembly | R85 | R140 |
| Optional Extras | R0 | R65 |
| **TOTAL** | **R1,010** | **R2,520** |

---

## Quick Shopping Checklist

### Step 1: Thermocouples (do this first - longest lead time)

**Option A - RS Components Order:**
- [ ] 3x RS Part# 3971264 (Type K MI, 150mm, 3mm)
- [ ] Or browse: [za.rs-online.com/thermocouples](https://za.rs-online.com/web/c/automation-control-gear/sensors/thermocouples/)

**Option B - Custom Quote:**
- [ ] Email Thermon SA: salessa@energisolutionsafrica.com
- [ ] Or call: 011 966 9800 (JHB) / 021 762 8995 (CPT)
- [ ] Use quote template from THERMOCOUPLE_SPEC.md

### Step 2: Electronics (Communica/Netram/etc)
- [ ] 3x MAX31855 thermocouple amplifier module
- [ ] 1x Jumper wire kit (Dupont cables)
- [ ] 1x Perfboard 5x7cm
- [ ] 1x Heat shrink tubing assortment
- [ ] 1x Pack M3 brass standoffs 10mm
- [ ] 1x USB A-B cable 2m
- [ ] (Optional) 1x SSD1306 0.96" OLED display

### Step 3: Enclosure (Communica/Mantech/Builders)
- [ ] 1x ABS project box ~150x100x50mm
- [ ] 1x Cable gland PG9 (or rubber grommet)
- [ ] (Optional) 3x Panel mount K-type socket

---

## Supplier Contact Directory

### Thermocouples (Custom/Industrial)

| Supplier | Phone | Website | Notes |
|---|---|---|---|
| Thermon SA (JHB) | 011 966 9800 | thermon.co.za | Custom manufacture |
| Thermon SA (CPT) | 021 762 8995 | thermon.co.za | Custom manufacture |
| Thermocouple Products | - | thermocoupleproducts.co.za | Edenvale, custom |
| RS Components | 011 691 9300 | za.rs-online.com | Stock items |
| Temperature Controls | - | tempcon.co.za | Since 1952 |

### Electronics

| Supplier | Phone | Website |
|---|---|---|
| Communica | 011 792 7646 | communica.co.za |
| Mantech | 011 452 1935 | mantech.co.za |
| Netram | - | netram.co.za |
| Micro Robotics | - | robotics.org.za |
| DIY Electronics | - | diyelectronics.co.za |

### Enclosures & Hardware

| Supplier | Website |
|---|---|
| Communica | communica.co.za |
| Mantech | mantech.co.za |
| Builders Warehouse | builders.co.za |

---

## Important Notes

### Thermocouple Selection Criteria

**MUST HAVE:**
- [x] K-type (Chromel/Alumel)
- [x] Insertion/probe style with stainless steel sheath
- [x] Closed tip (not exposed wires)
- [x] 2-4mm probe diameter (3mm ideal)
- [x] Miniature K-type connector (flat blade, yellow)
- [x] 1m+ cable length

**AVOID:**
- Surface mount / washer / ring style
- Exposed junction (bare wires)
- Probes thicker than 6mm (too slow)
- "Air probes" with plastic handles

### Why 3mm Diameter Matters

From coffee roasting research ([Barista Hustle](https://www.baristahustle.com/lesson/htr-1-06-temperature-probes/), [Scott Rao](https://www.scottrao.com/blog/be-careful-when-interpreting-bean-data)):

| Diameter | Response | Coffee Roasting Suitability |
|---|---|---|
| 1.5mm | Very fast | Fragile, may break |
| **3mm** | **Fast (4-6s)** | **Ideal balance** |
| 5mm | Medium (8-12s) | Acceptable |
| 6mm+ | Slow (15s+) | Too much thermal lag |

Thicker probes cause "thermal lag" which:
- Delays detection of first crack
- Smooths out the roast curve (hides problems)
- Makes RoR (Rate of Rise) calculations inaccurate

---

**Next Steps After Shopping:**
1. Assembly → See [WIRING.md](WIRING.md)
2. Firmware setup → See [arduino-firmware/README.md](../arduino-firmware/README.md)
3. Artisan config → See [ARTISAN_INTEGRATION.md](ARTISAN_INTEGRATION.md)

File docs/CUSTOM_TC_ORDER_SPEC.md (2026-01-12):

# Custom K-Type Thermocouple Order Specification

**Project:** Milk Depot Coffee Roaster Temperature Monitoring System
**Date:** January 2026
**Quantity:** 6 probes (3 different lengths, 2 of each)

---

## Application Summary

Coffee drum roaster temperature monitoring with three measurement points:

| Position | Location | Environment | Max Operating Temp |
|---|---|---|---|
| BT | Inside roasting drum, immersed in coffee beans | Direct bean contact, agitation, hot air | 250°C |
| ET | Exhaust duct, 10-15cm from drum exit | Hot air flow, no contact with beans | 300°C |
| FT | Near gas burner, measuring flame area | Radiant heat, occasional flame proximity | 450°C |

**Integration:** MAX31855 thermocouple amplifier → Arduino UNO → Artisan roasting software

**Note:** Ordering multiple lengths to determine optimal fit for each position, plus spares.

---

## Common Specifications (All 6 Probes)

| Parameter | Specification |
|---|---|
| **Thermocouple Type** | K-Type (Chromel-Alumel) per IEC 60584 |
| **Accuracy Class** | Class 1 preferred (±1.5°C), Class 2 acceptable (±2.5°C) |
| **Sheath Material** | AISI 316L Stainless Steel (food-grade, corrosion resistant) |
| **Junction Type** | Grounded (junction welded to sheath tip for fast response) |
| **Tip Style** | Closed, rounded (sealed, no exposed elements) |
| **Cable Insulation** | Fiberglass inner, stainless steel overbraid outer |
| **Cable Temperature Rating** | 700°C at sheath transition |
| **Cable Termination** | Bare wire ends, tinned (for screw terminal connection) |
| **Mounting** | Threaded compression fitting with lock nut (see mounting section) |

---

## Order Summary

**6 probes in 3 lengths (2 of each):**

| Qty | Sheath Length | Sheath Diameter | Temp Rating | Mounting Thread |
|-----|---|---|---|---|
| 2 | 35mm | 2.5mm | 700°C | M8 x 1.0 |
| 2 | 50mm | 3.0mm | 700°C | M8 x 1.0 |
| 2 | 70mm | 3.0mm | 700°C | M8 x 1.0 |

**Total: 6 probes**

**Design rationale:**
- 35mm probes: 2.5mm diameter for fastest response (likely BT position)
- 50mm/70mm probes: 3.0mm standard diameter for durability
- All probes 700°C rated: fully interchangeable for any position

---

## Probe Specifications by Size

### 35mm Probes (Qty: 2) - Fast Response

| Parameter | Specification | Rationale |
|---|---|---|
| **Sheath Diameter** | 2.5mm (±0.2mm) | Fastest response for BT position |
| **Sheath Length** | 35mm | Compact fit into drum |
| **Cable Length** | 2.0 meters | Reach to electronics enclosure |
| **Temperature Range** | -40°C to +700°C | Full interchangeability |
| **Response Time (t63)** | ≤3 seconds in moving air | Critical for first crack detection |

### 50mm Probes (Qty: 2) - Standard

| Parameter | Specification | Rationale |
|---|---|---|
| **Sheath Diameter** | 3.0mm (±0.2mm) | Balance of response and durability |
| **Sheath Length** | 50mm | Medium insertion depth |
| **Cable Length** | 2.0 meters | Reach to electronics enclosure |
| **Temperature Range** | -40°C to +700°C | Full interchangeability |
| **Response Time (t63)** | ≤5 seconds in moving air | Adequate for monitoring |

### 70mm Probes (Qty: 2) - Deep Insertion

| Parameter | Specification | Rationale |
|---|---|---|
| **Sheath Diameter** | 3.0mm (±0.2mm) | Durability at high temps |
| **Sheath Length** | 70mm | Deeper insertion, positioning flexibility |
| **Cable Length** | 2.0 meters | Reach to electronics enclosure |
| **Temperature Range** | -40°C to +700°C | Full interchangeability |
| **Response Time (t63)** | ≤5 seconds in moving air | Adequate for monitoring |

**All probes - Construction:**
- Smooth sheath surface (no burrs or rough welds)
- Flexible cable transition to handle movement and vibration
- Quality junction weld for thermal cycling durability

---

## Cable Termination

All probes terminate in **bare wire ends** for connection to MAX31855 screw terminals:

```
Cable End: Bare conductors, tinned
Wire Length: 20-30mm exposed from cable sheath
Polarity Marking: Clear color coding or labeling

  ══════════════╗
  SS Overbraid  ║
  + Fiberglass  ║
  ══════════════╝
        │
        ├──── + (Yellow) ──── Chromel (positive)
        │
        └──── - (Red) ─────── Alumel (negative)

  Wire gauge: Appropriate for thermocouple type (typically 24-20 AWG)
  Tinning: Solder-tinned ends for easy insertion into screw terminals
```

**Important:** K-type polarity is counter-intuitive:
- **Yellow wire = Positive (+)** = Chromel
- **Red wire = Negative (-)** = Alumel

Please ensure clear polarity marking on each probe.

---

## Mounting Specification

Probes require a **threaded fitting with lock nut** to mount through the roaster casing:

```
                     Roaster Wall (steel, ~2-3mm thick)
                            │
    ┌───────────────────────┼───────────────────────┐
    │                       │                       │
    │   INSIDE ROASTER      │      OUTSIDE          │
    │                       │                       │
    │         Probe Tip     │                       │
    │            ○──────────┼──────┬────────────────│───► To cable
    │                       │      │                │
    │                       │   ┌──┴──┐             │
    │                       │   │ NUT │ Lock nut    │
    │                       │   └──┬──┘             │
    │                       │      │                │
    │                    ┌──┴──────┴──┐             │
    │                    │   FITTING   │            │
    │                    │  (threaded) │            │
    │                    └─────────────┘            │
    │                                               │
    └───────────────────────────────────────────────┘
```

### Fitting Requirements

| Parameter | 35mm Probes (2.5mm dia) | 50mm & 70mm Probes (3.0mm dia) |
|---|---|---|
| **Thread Size** | M8 x 1.0 | M8 x 1.0 |
| **Fitting Type** | Compression or brazed | Compression or brazed |
| **Nut Included** | Yes - hex lock nut | Yes - hex lock nut |
| **Sealing** | Metal-to-metal or with washer | Metal-to-metal or with washer |
| **Drill Size** | 8mm hole in roaster wall | 8mm hole in roaster wall |

**Alternative thread sizes acceptable:** M6 x 1.0 (if M8 not available for 2.5mm sheath)

### Mounting Style Options (in order of preference)

1. **Adjustable Compression Fitting** (preferred)
   - Allows depth adjustment after installation
   - Probe can be repositioned without disassembly
   - Ferrule seals around sheath

2. **Fixed Brazed/Welded Fitting**
   - Fitting permanently attached to sheath
   - Fixed insertion depth
   - More robust, no ferrule to wear

### Insertion Depth

The fitting should be positioned to allow:
- **Minimum 20mm** of sheath protruding inside roaster (measurement point)
- **Remaining sheath length** transitions to cable outside

```
Example for 50mm probe:

    Inside Roaster    │ Wall │    Outside
                      │      │
    ←─── 25-30mm ────►│ 3mm  │←── 17-22mm ──► to cable
                      │      │
         ○────────────┼──────┼────────╮
         Tip          │ Fit  │        Cable
                      │      │
```

---

## Construction Diagram

```
         Sheath (316L SS)
        ┌─────────────────────┐
   Tip  │  Grounded junction  │  Threaded     Transition
  (seal)│  welded at tip      │  Fitting      to cable
    ○───┴─────────────────────┴────┬────────────╮
                                   │            │
    |←── Sheath Length ──────────→||            │
         (35mm / 50mm / 70mm)    M8x1.0         │
                                 + Nut          │
                                                │
                                         ╭──────┴───────╮
                                         │ SS Overbraid │
                                         │ + Fiberglass │
                                         │    Cable     │
                                         │   (2.0m)     │
                                         ╰──────┬───────╯
                                                │
                                         ╭──────┴───────╮
                                         │  Bare Wire   │
                                         │   Tinned     │
                                         │   + / -      │
                                         ╰──────────────╯
```

---

## Quality Requirements

| Test | Requirement | Method |
|---|---|---|
| Insulation Resistance | >100MΩ at 500VDC | Megger test |
| Continuity | <10Ω loop resistance | Multimeter |
| Calibration Check | Within Class tolerance at 0°C and 200°C | Ice bath, boiling water |
| Visual Inspection | No cracks, proper crimp, clean welds | Visual |

---

## Materials Certification

Please provide:
- [ ] Material certificate for 316L stainless steel sheath
- [ ] Thermocouple wire certificate (Chromel/Alumel composition)
- [ ] Calibration certificate or test data (optional but appreciated)

---

## Delivery Requirements

- Individual labeling: Each probe marked with length and diameter (e.g., "35mm/2.5mm", "70mm/3.0mm")
- Protective packaging: Probe tips and threaded fittings protected during shipping
- Documentation: Basic datasheet or drawing of final product
- Lock nuts: Included with each probe (6 total)

---

## Contact Information

**Project:** Milk Depot Coffee Roaster
**Location:** South Africa
**Email:** [your email]
**Phone:** [your phone]

---

## Notes for Manufacturer

1. **Food Contact:** Probes will contact coffee beans. 316L SS is required. No lubricants, oils, or coatings that could contaminate food.

2. **Two Diameter Variants (all 700°C rated):**
   - 35mm probes: 2.5mm diameter
   - 50mm & 70mm probes: 3.0mm diameter

3. **Mounting Hardware:** Each probe requires threaded fitting (M8 x 1.0 preferred) with hex lock nut included. Compression style preferred for adjustable insertion depth.

4. **Cable Termination:** Bare tinned wire ends, NOT plug connectors. Will connect directly to screw terminals on amplifier board.

5. **Polarity Marking:** Critical - please clearly mark polarity on cable. K-type: Yellow = +/Chromel, Red = -/Alumel.

6. **Labelling:** Mark each probe with: sheath length (35/50/70mm) and diameter (2.5/3.0mm).

---

*Specification Version: 1.0*
*Project: Milk Depot Coffee Roaster*

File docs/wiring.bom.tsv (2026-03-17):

Id | Description | Qty | Unit | Designators
1 | Cable, 1 wires | 2 | m | C1a, C1b, C2a, C2b, USB, W1, W10, W11, W12, W13, W14, W2, W3, W4, W5, W6, W7, W8, W9
2 | Cable, 2 wires | 3 | m | W15, W16
3 | Connector, 1.3" SH1106 OLED, female, 4 pins | 1 |  | OLED
4 | Connector, Arduino Nano (USB-C), male, 9 pins | 1 |  | Nano
5 | Connector, Ceramic Capacitor, male, 2 pins | 2 |  | C1, C2
6 | Connector, K-Type Thermocouple, male, 2 pins | 2 |  | TC_BT, TC_ET
7 | Connector, MAX31855 Module, female, 7 pins | 2 |  | BT, ET
8 | Connector, Raspberry Pi 4, female, 1 pins | 1 |  | RPi

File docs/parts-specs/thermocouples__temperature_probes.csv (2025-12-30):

Datasheet | Image | DK Part # | Mfr Part # | Mfr | Supplier | Description | Stock | Price | @ qty | Min Qty | Package | Series | Product Status | Element Type | Temperature Range | Length - Lead Wire | Conductor Type | Terminal Type | URL
- | //mm.digikey.com/Volume0/opasdata/d220001/medias/images/6402/TC-K-TYPE.jpg | 1188-TC-K-TYPE-ND | TC-K-TYPE | Olimex LTD | Olimex LTD | SENSOR TEMP -50~700C CONNECTOR | 1 101 | 30.33 | 0 | 1 | Bulk | - | Active | K - Type | -50°C ~ 700°C | - | Non-Grounded | Connector | https://www.digikey.co.za/en/products/detail/olimex-ltd/TC-K-TYPE/21662067
//mm.digikey.com/Volume0/opasdata/d220001/medias/docus/1178/240-080_Web.pdf | //mm.digikey.com/Volume0/opasdata/d220001/medias/images/2299/240-080.JPG | 1286-1099-ND | 240-080 | Digilent, Inc. | Digilent, Inc. | THERMOCOUPLE WIRE K-TYPE 1M | 1 348 | 442.09 | 0 | 1 | Bulk | - | Active | K - Type | -73°C ~ 482°C | 3.281' (1m) | - | Exposed Lead Wires | https://www.digikey.co.za/en/products/detail/digilent-inc/240-080/5418219
- | //mm.digikey.com/Volume0/opasdata/d220001/medias/images/6402/TC-K-TYPE-1.5M.jpg | 1188-TC-K-TYPE-1.5M-ND | TC-K-TYPE-1.5M | Olimex LTD | Olimex LTD | SENSOR TEMP -50~700C LEAD WIRE | 54 | 40.38 | 0 | 1 | Bulk | - | Active | K - Type | -50°C ~ 700°C | 4.921' (1.5m) | Grounded | Connector | https://www.digikey.co.za/en/products/detail/olimex-ltd/TC-K-TYPE-1-5M/21662574
https://www.playingwithfusion.com/include/getfile.php?fileid=7092 | //mm.digikey.com/Volume0/opasdata/d220001/medias/images/2780/MFG_FDQ-10001-K_primary.jpg | 3405-FDQ-10001-K-ND | FDQ-10001-K | Fusion DAQ | Playing With Fusion, Inc | 8-CHANNEL K-TYPE ANALOG THERMOCO | 3 | Active | 0 | 1 | Retail Package | - | Active | K - Type | -260°C ~ 1000°C | 5.000" (127.00mm) | - | Connector | https://www.digikey.co.za/en/products/detail/playing-with-fusion-inc/FDQ-10001-K/13998047
- | //mm.digikey.com/Volume0/opasdata/d220001/medias/images/6402/TC-K-TYPE-0.4M.jpg | 1188-TC-K-TYPE-0.4M-ND | TC-K-TYPE-0.4M | Olimex LTD | Olimex LTD | SENSOR TEMP -50~700C LEAD WIRE | 22 | 30.33 | 0 | 1 | Bulk | - | Active | K - Type | -50°C ~ 700°C | 15.75" (400.00mm) | Grounded | Connector | https://www.digikey.co.za/en/products/detail/olimex-ltd/TC-K-TYPE-0-4M/21662657
//mm.digikey.com/Volume0/opasdata/d220001/medias/docus/797/79696034.pdf | //mm.digikey.com/Volume0/opasdata/d220001/medias/images/1064/79696034.jpg | 966-1062-ND | 79696034 | Crouzet | Crouzet | PROBE THERMOCOUPLE K-TYPE 1100C | 0 | 1852.23 | 0 | 1 | Bulk | - | Obsolete | K - Type | 0 ~ 1100°C | 6.562' (2m) | Non-Grounded | Exposed Lead Wires | https://www.digikey.co.za/en/products/detail/crouzet/79696034/2239477
https://assets.omron.com/m/755905f55b6cf81e/original/E52-Temperature-Sensor-Datasheet.pdf | - | 236-E52-CA20AY D=1.6 2M-ND | E52-CA20AY D=1.6 2M | Omron Automation and Safety | Omron Automation and Safety | T- COUPLE K-TYPE L 20CM 2M | 0 | 3279.18 | 0 | 1 | Bulk | * | Active | - | - | - | - | - | https://www.digikey.co.za/en/products/detail/omron-automation-and-safety/E52-CA20AY-D-1-6-2M/12264443
- | - | 2770-745687-K030-ND | 745687-K030 | NI | NI | K-TYPE THERMOCOUPLE WIRE (32 DEG | 0 | 4542.54 | 0 | 1 | Bulk | - | Active | - | - | - | - | - | https://www.digikey.co.za/en/products/detail/ni/745687-K030/18710694

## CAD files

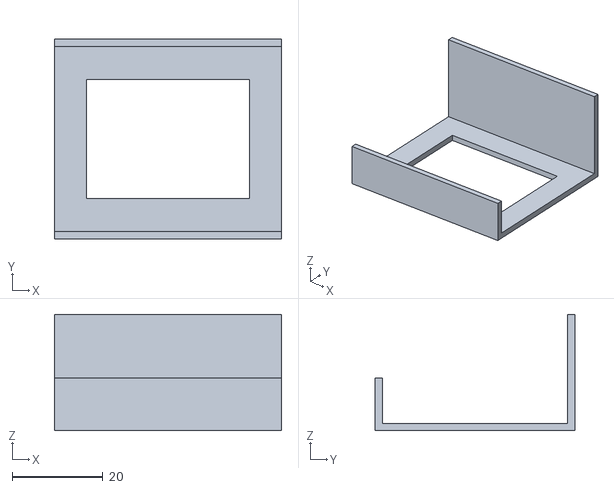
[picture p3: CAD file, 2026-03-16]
3d-prints/display-testpanel.stl
50.0 x 44.0 x 25.6

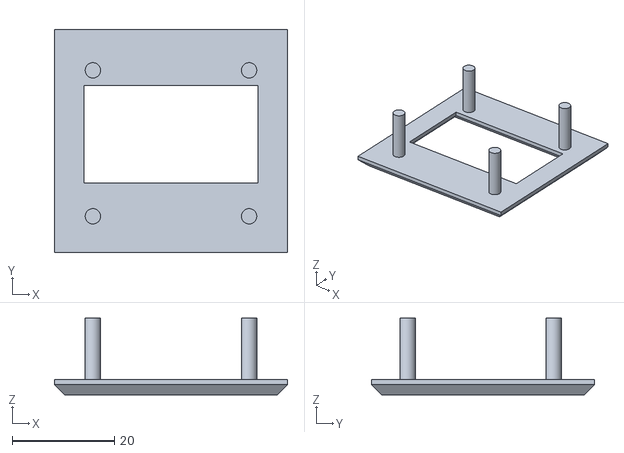
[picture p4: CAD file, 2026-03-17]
FreeCad/oled-1.3inch-holder-bezel-BodyChamfer007.stl
45.5 x 43.6 x 15.0

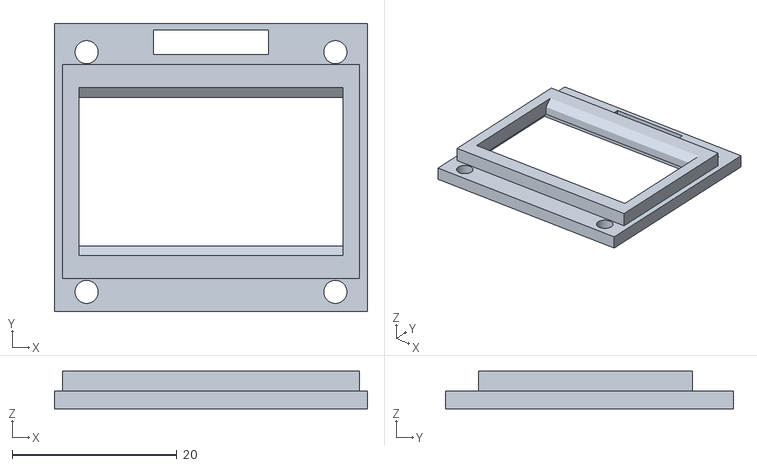
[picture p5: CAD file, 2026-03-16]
3d-prints/displayframe-oled-1_3inch-sh1106.stl
38.0 x 35.0 x 4.60

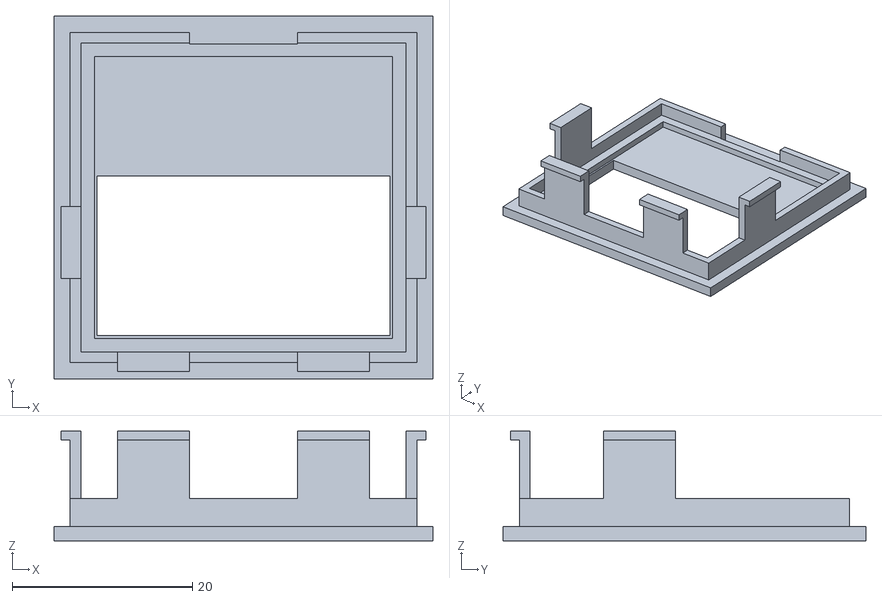
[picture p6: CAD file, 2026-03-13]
3d-prints/oled-bezel.stl
42.1 x 40.3 x 12.2

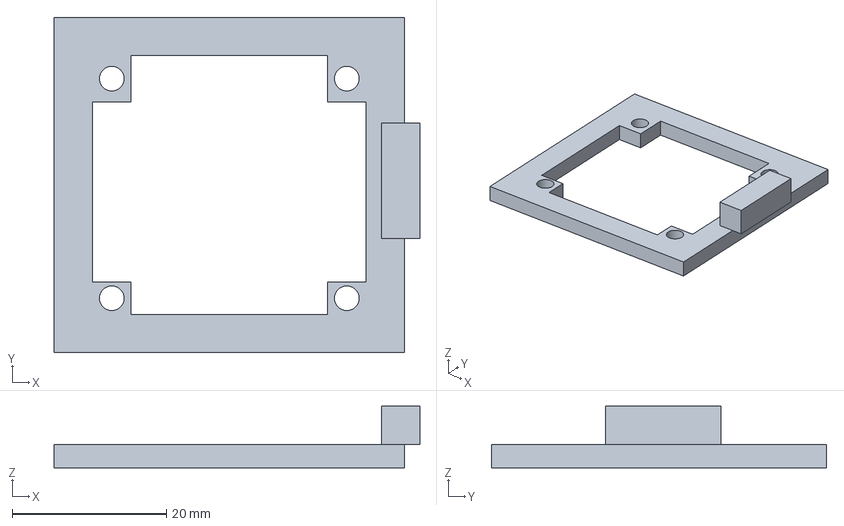
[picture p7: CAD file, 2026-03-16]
FreeCad/oled-1.3inch-holder2.FCStd
47.5 x 43.5 x 8.00 mm

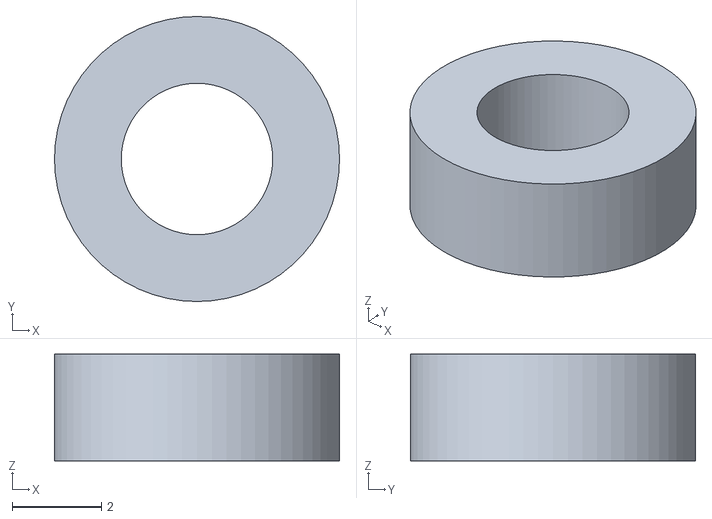
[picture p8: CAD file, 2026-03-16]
3d-prints/display-washer.stl
6.40 x 6.40 x 2.40

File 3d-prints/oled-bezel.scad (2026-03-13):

// OLED 1.3" Snap-Fit Panel Bezel
// For Milk Depot Coffee Roaster enclosure lid
//
// Mounts a 1.3" SH1106/SSD1306 I2C OLED display into a rectangular
// cutout on the enclosure lid. The bezel sits on the outside, snap
// tabs grip behind the lid.
//
// Print settings: 0.2mm layer height, no supports needed,
// PLA or PETG, 100% infill on snap tabs for strength.

// === PARAMETERS (all in mm) ===

// OLED module dimensions (from datasheet)
pcb_w = 35.5;       // PCB width
pcb_h = 33.7;       // PCB height
pcb_t = 1.6;        // PCB thickness (just the board)
view_w = 31.5;      // Viewable area width
view_h = 16.7;      // Viewable area height

// The OLED glass/viewable area is offset from center of PCB.
// From the datasheet: glass is near the bottom of the PCB,
// with the header pins at the top.
// Vertical offset of viewable area center from PCB center:
// PCB center is at 33.7/2 = 16.85mm from bottom
// View area center is at 3.04 + 14.70/2 = 10.39mm from bottom
// So offset = 16.85 - 10.39 = 6.46mm (view area is below PCB center)
view_offset_y = 6.46;

// Header pins protrude from the top edge of the PCB.
// We need clearance in the bezel for them.
pin_clearance_w = 12;  // width of pin header area
pin_clearance_h = 3;   // how far pins extend beyond PCB edge

// Enclosure lid
lid_t = 2.5;         // lid thickness (typical ABS project box)

// Bezel design
bezel_border = 3.0;  // border width around the window
bezel_t = 1.6;       // bezel face thickness
pcb_clearance = 0.3; // gap around PCB for easy insertion

// Snap tab design
tab_w = 8;           // width of each snap tab
tab_depth = 5;       // how far tabs extend behind the lid
tab_t = 1.2;         // tab wall thickness
hook_h = 1.0;        // hook overhang that grips behind lid
hook_angle = 35;     // lead-in angle for easy insertion

// PCB shelf (ledge the PCB rests on inside the bezel)
shelf_w = 1.5;       // shelf width (inward from pocket wall)
shelf_depth = 1.0;   // shelf thickness below PCB

// === DERIVED DIMENSIONS ===

pocket_w = pcb_w + pcb_clearance * 2;
pocket_h = pcb_h + pcb_clearance * 2;

outer_w = pocket_w + bezel_border * 2;
outer_h = pocket_h + bezel_border * 2;

// Window in the bezel face (slightly larger than viewable area)
window_w = view_w + 1.0;
window_h = view_h + 1.0;

// Total depth behind the bezel face: shelf + PCB + lid + snap hook
total_depth = bezel_t + shelf_depth + pcb_t + lid_t + tab_depth;

// === MODULES ===

module bezel_face() {
    // Front face with window cutout
    difference() {
        cube([outer_w, outer_h, bezel_t]);

        // Window opening, offset to match viewable area position
        translate([
            outer_w/2 - window_w/2,
            outer_h/2 - window_h/2 - view_offset_y,
            -0.1
        ])
        cube([window_w, window_h, bezel_t + 0.2]);
    }
}

module pcb_pocket() {
    // Walls that form the pocket for the PCB
    pocket_depth = shelf_depth + pcb_t + 0.5;  // slight extra clearance

    difference() {
        // Outer pocket walls
        translate([bezel_border - tab_t, bezel_border - tab_t, bezel_t])
        cube([pocket_w + tab_t*2, pocket_h + tab_t*2, pocket_depth]);

        // Inner pocket (PCB sits here)
        translate([bezel_border, bezel_border, bezel_t + shelf_depth])
        cube([pocket_w, pocket_h, pocket_depth + 0.1]);

        // Shelf cutout — remove inner portion but leave shelf_w ledge
        translate([
            bezel_border + shelf_w,
            bezel_border + shelf_w,
            bezel_t - 0.1
        ])
        cube([
            pocket_w - shelf_w*2,
            pocket_h - shelf_w*2,
            shelf_depth + 0.2
        ]);

        // Pin header clearance notch at the top of the pocket
        translate([
            outer_w/2 - pin_clearance_w/2,
            outer_h - bezel_border - 0.1,
            bezel_t - 0.1
        ])
        cube([pin_clearance_w, bezel_border + tab_t + 0.2, pocket_depth + 0.2]);
    }
}

module snap_tab(length) {
    // Single cantilever snap tab with hook
    // Oriented along Z axis, hook at the bottom (max Z)

    tab_total = lid_t + tab_depth;

    // Main cantilever beam
    cube([tab_w, tab_t, tab_total]);

    // Hook at the end (angled lead-in + flat grip)
    translate([0, -hook_h, tab_total - hook_h])
    difference() {
        cube([tab_w, tab_t + hook_h, hook_h]);

        // Angled lead-in chamfer
        translate([-0.1, 0, hook_h])
        rotate([hook_angle, 0, 0])
        cube([tab_w + 0.2, (tab_t + hook_h) * 2, hook_h * 2]);
    }
}

module snap_tabs() {
    pcb_pocket_depth = shelf_depth + pcb_t + 0.5;
    tab_z = bezel_t + pcb_pocket_depth;

    // Left tab
    translate([outer_w/2 - tab_w/2 - 10, bezel_border - tab_t, tab_z])
    rotate([0, 0, 0])
    snap_tab(tab_w);

    // Right tab
    translate([outer_w/2 - tab_w/2 + 10, bezel_border - tab_t, tab_z])
    rotate([0, 0, 0])
    snap_tab(tab_w);

    // Bottom tab (opposite side from pins)
    translate([bezel_border - tab_t, outer_h/2 - tab_w/2 - 5, tab_z])
    rotate([0, 0, -90])
    translate([-tab_w, 0, 0])
    snap_tab(tab_w);

    // Top tab (near pins — shorter to avoid pin interference)
    translate([outer_w - bezel_border + tab_t, outer_h/2 - tab_w/2 - 5, tab_z])
    rotate([0, 0, 90])
    snap_tab(tab_w);
}

// === ASSEMBLY ===

// Print orientation: bezel face down on bed (face is the flat pretty side)
// Snap tabs point upward

color("DarkSlateGray") {
    bezel_face();
    pcb_pocket();
    snap_tabs();
}

// === CUTOUT TEMPLATE (for marking the lid) ===
// Uncomment to render just the cutout shape for the lid

// module lid_cutout_template() {
//     // This is the rectangular hole to cut in the enclosure lid
//     // Print this flat and use as a drilling/cutting template
//     difference() {
//         translate([-5, -5, 0])
//         cube([pocket_w + 10 + tab_t*2, pocket_h + 10 + tab_t*2, 0.6]);
//
//         translate([5, 5, -0.1])
//         cube([pocket_w + tab_t*2, pocket_h + tab_t*2, 0.8]);
//     }
//     // Center crosshair
//     translate([5 + (pocket_w + tab_t*2)/2 - 0.3, -5, 0])
//     cube([0.6, pocket_h + 10 + tab_t*2, 0.6]);
//     translate([-5, 5 + (pocket_h + tab_t*2)/2 - 0.3, 0])
//     cube([pocket_w + 10 + tab_t*2, 0.6, 0.6]);
// }
// lid_cutout_template();

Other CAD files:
FreeCad/oled-1.3inch-holder-bezel.FCStd
FreeCad/oled-1.3inch-holder.FCStd
FreeCad/oled-1.3inch-holder-bezel.3mf
FreeCad/oled-1.3inch-holder-bezel.stl

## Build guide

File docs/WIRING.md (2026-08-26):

# Wiring & Assembly Guide

Complete wiring and assembly reference for the Milk Depot Coffee Roaster temperature monitoring system.

**Updated:** 2-channel design with Arduino Nano, 2x MAX31855, 1.3" SH1106 OLED.

## System Overview

```
                    ┌─────────────────────────────────────────────────┐
                    │                     ROASTER                     │
                    │                                                 │
                    │    [DRUM]◄───── BT Probe (35mm/2.5mm)          │
                    │       │                                         │
                    │       ▼                                         │
                    │   [EXHAUST]◄─── ET Probe (50mm/3.0mm)          │
                    │                                                 │
                    └──────┬───────────────────┬──────────────────────┘
                           │                   │
                           │ 1.5m K-type        │ 1.5m K-type
                           │ bare tinned wire   │ bare tinned wire
                           │                   │
┌──────────────────────────┴───────────────────┴──────────────────────┐
│                           ENCLOSURE (61×80×23mm)                    │
│                                                                     │
│   ┌─────────────────────────────────────────────────────────────┐   │
│   │              50×70mm Veroboard                              │   │
│   │                                                             │   │
│   │   ┌──────────────┐   ┌─────────┐   ┌─────────┐            │   │
│   │   │ Arduino Nano │   │MAX31855 │   │MAX31855 │            │   │
│   │   │   (USB-C)    │   │   BT    │   │   ET    │            │   │
│   │   │              │   │  ┌─┐    │   │  ┌─┐    │            │   │
│   │   │   D13──SCK──►│──►│  │C1    │   │  │C2    │            │   │
│   │   │   D12◄─DO───◄│──◄│  └─┘    │   │  └─┘    │            │   │
│   │   │   D10──CS───►│──►│  100nF  │   │  100nF  │            │   │
│   │   │   D9───CS───►│───│─────────│──►│         │            │   │
│   │   │   A4──SDA──► │   │  TC+ TC-│   │  TC+ TC-│            │   │
│   │   │   A5──SCL──► │   └────┬──┬─┘   └────┬──┬─┘            │   │
│   │   │   5V──VCC──► │        │  │          │  │               │   │
│   │   │   GND─GND──► │   BT probe      ET probe               │   │
│   │   └──────┬───────┘                                         │   │
│   │          │ USB-C                                           │   │
│   └──────────┼─────────────────────────────────────────────────┘   │
│              │                         ┌────────────┐              │
│              │                         │ 1.3" OLED  │ Front panel  │
│              │                         │  (I2C)     │ bezel mount  │
│              │                         └────────────┘              │
└──────────────┼─────────────────────────────────────────────────────┘
               │
          USB-C Cable (2m)
               │
      ┌────────┴────────┐
      │  RASPBERRY PI 4 │
      │  10.0.10.102    │
      │  [Artisan SW]   │
      └─────────────────┘
```

## Arduino Nano Pinout

```
              Arduino Nano (USB-C variant)
              Top view, USB connector at top

         Left Header              Right Header
         ───────────              ────────────
    TX ─ │ D1          D13 │ ─ SPI SCK ──► BT SCK, ET SCK
    RX ─ │ D0          3V3 │
         │ RST        AREF │
   GND ◄─│ GND          A0 │
         │ D2           A1 │
         │ D3           A2 │
         │ D4           A3 │
         │ D5      SDA  A4 │ ─ I2C SDA ──► OLED SDA
         │ D6      SCL  A5 │ ─ I2C SCL ──► OLED SCL
         │ D7           A6 │
         │ D8           A7 │
  CS ET ─│ D9           5V │ ─ VCC ──► BT, ET, OLED
  CS BT ─│ D10         RST │
         │ D11         GND │ ─ GND ──► BT, ET, OLED
SPI DO ◄─│ D12         VIN │
         ────────┬──────────
                 │
              USB-C
```

## Pin Assignment Table

| Arduino Pin | Function | Wire Colour | Connected To |
|---|---|---|---|
| D13 | SPI SCK | Yellow | BT SCK + ET SCK |
| D12 | SPI MISO | Green | BT DO + ET DO |
| D10 | CS_BT | Blue | BT CS (Bean Temp) |
| D9 | CS_ET | Violet | ET CS (Exhaust Temp)  |
| A4 | I2C SDA | White | OLED SDA |
| A5 | I2C SCL | Orange | OLED SCL |
| 5V | Power | Red | BT VCC, ET VCC, OLED VCC |
| GND | Ground | Black | BT GND, ET GND, OLED GND |
| USB-C | Serial/Power| — | RPi 4 via USB cable |

## MAX31855 Module Wiring

Both modules share the SPI bus (SCK, DO) but have individual chip select (CS) lines.

```
┌─────────────────────────┐       ┌─────────────────────────┐
│    MAX31855 - BT        │       │    MAX31855 - ET        │
│    (Bean Temperature)   │       │    (Exhaust Temperature) │
│                         │       │                         │
│  VCC ─── 5V (Red)      │       │  VCC ─── 5V (Red)      │
│  GND ─── GND (Black)   │       │  GND ─── GND (Black)   │
│  SCK ─── D13 (Yellow)  │       │  SCK ─── D13 (Yellow)  │
│  DO  ─── D12 (Green)   │       │  DO  ─── D12 (Green)   │
│  CS  ─── D10 (Blue)    │       │  CS  ─── D9 (Violet)   │
│                         │       │                         │
│  TC+ ─── Yellow wire   │       │  TC+ ─── Yellow wire   │
│  TC- ─── Red wire ⚠    │       │  TC- ─── Red wire ⚠    │
│         (red=NEGATIVE!) │       │         (red=NEGATIVE!) │
│                         │       │                         │
│  ┌─┐ 100nF (C1)        │       │  ┌─┐ 100nF (C2)        │
│  └─┘ across VCC/GND    │       │  └─┘ across VCC/GND    │
└─────────────────────────┘       └─────────────────────────┘
```

> **⚠ POLARITY WARNING:** K-type thermocouple red wire is **NEGATIVE**. Reversing polarity causes readings to go negative as temperature increases.

## Decoupling Capacitors

Each MAX31855 module gets a 100nF (code "104") ceramic capacitor soldered directly across VCC and GND, as close to the module pins as possible. This filters high-frequency noise on the power supply.

| Cap | Module | Connection |
|-----|---|---|
| C1  | BT | BT VCC to BT GND |
| C2  | ET | ET VCC to ET GND |

## OLED Display (I2C)

The 1.3" SH1106 OLED mounts in a bezel on the enclosure front panel, connected via 4 wires to the veroboard.

```
    1.3" SH1106 OLED               Arduino Nano
    ┌─────────────┐                 ┌──────────┐
    │ VCC ────────│── Red ──────────┤ 5V       │
    │ GND ────────│── Black ────────┤ GND      │
    │ SDA ────────│── White ────────┤ A4       │
    │ SCL ────────│── Orange ───────┤ A5       │
    └─────────────┘                 └──────────┘

    OLED PCB: 35.5 × 33.6mm
    Screen:   35 × 19.5mm (128×64 pixels)
    Mounting: 4× Essentra 27PIF0045B push-in fasteners
```

## Complete Wire List

| # | From | To | Colour | Length | Notes |
|---|---|----|---|---|---|
| W1 | Nano D13 | BT SCK | Yellow | ~5cm | SPI clock |
| W2 | Nano D13 | ET SCK | Yellow | ~8cm | SPI clock |
| W3 | Nano D12 | BT DO | Green | ~5cm | SPI data |
| W4 | Nano D12 | ET DO | Green | ~8cm | SPI data |
| W5 | Nano D10 | BT CS | Blue | ~5cm | Chip select BT |
| W6 | Nano D9 | ET CS | Violet | ~8cm | Chip select ET |
| W7 | Nano A4 | OLED SDA | White | ~15cm | I2C data (to panel) |
| W8 | Nano A5 | OLED SCL | Orange | ~15cm | I2C clock (to panel) |
| W9 | Nano 5V | BT VCC | Red | ~5cm | Power |
| W10 | Nano 5V | ET VCC | Red | ~8cm | Power |
| W11 | Nano 5V | OLED VCC | Red | ~15cm | Power (to panel) |
| W12 | Nano GND | BT GND | Black | ~5cm | Ground |
| W13 | Nano GND | ET GND | Black | ~8cm | Ground |
| W14 | Nano GND | OLED GND | Black | ~15cm | Ground (to panel) |
| W15 | TC_BT | BT TC+/TC- | YE/RD | 1.5m | BT thermocouple lead |
| W16 | TC_ET | ET TC+/TC- | YE/RD | 1.5m | ET thermocouple lead |
| USB | RPi USB | Nano USB-C | — | 2m | Power + serial data |

## Veroboard Assembly Layout

50×70mm stripboard. Strips run along the 70mm length (27 holes per strip, 19 strips).

### Component Placement (top view)

```
     Veroboard 50×70mm (copper strips run left-right →)
     Columns: A B C D E F G H I J K L M N O P Q R S
     ═══════════════════════════════════════════════════
 1 → ○ ○ ○ ○ ○ ○ ○ ○ ○ ○ ○ ○ ○ ○ ○ ○ ○ ○ ○
 2 → ○ ○ ○ ○ ○ ○ ○ ○ ○ ○ ○ ○ ○ ○ ○ ○ ○ ○ ○
 3 → ○ ○ ○ ○ ○ ○ ○ ○ ○ ○ ○ ○ ○ ○ ○ ○ ○ ○ ○
 4 → ○ ○ ○ ○ ○ ○ ○ ○ ○ ○ ○ ○ ○ ○ ○ ○ ○ ○ ○
     ┌─────────────────────────────────────────────────
     │ ZONE A: Arduino Nano (rows 5-19, cols C-H)
     │ Placed spanning cols C and H (0.6" DIP width)
     │ USB connector faces row 5 edge
 5 → ○ ○[TX  ○ ○ ○ ○ D13]○ ○ ○ ○ ○ ○ ○ ○ ○ ○ ○
 6 → ○ ○[RX  ○ ○ ○ ○ 3V3]○ ○ ○ ○ ○ ○ ○ ○ ○ ○ ○
 7 → ○ ○[RST ○ ○ ○ ○ REF]○ ○ ○ ○ ○ ○ ○ ○ ○ ○ ○
 8 → ○ ○[GND ○ ○ ○ ○  A0]○ ○ ○ ○ ○ ○ ○ ○ ○ ○ ○
 9 → ○ ○[D2  ○ ○ ○ ○  A1]○ ○ ○ ○ ○ ○ ○ ○ ○ ○ ○
10 → ○ ○[D3  ○ ○ ○ ○  A2]○ ○ ○ ○ ○ ○ ○ ○ ○ ○ ○
11 → ○ ○[D4  ○ ○ ○ ○  A3]○ ○ ○ ○ ○ ○ ○ ○ ○ ○ ○
12 → ○ ○[D5  ○ ○ ○ ○  A4]○ ○ ○ ○ ○ ○ ○ ○ ○ ○ ○  ← SDA
13 → ○ ○[D6  ○ ○ ○ ○  A5]○ ○ ○ ○ ○ ○ ○ ○ ○ ○ ○  ← SCL
14 → ○ ○[D7  ○ ○ ○ ○  A6]○ ○ ○ ○ ○ ○ ○ ○ ○ ○ ○
15 → ○ ○[D8  ○ ○ ○ ○  A7]○ ○ ○ ○ ○ ○ ○ ○ ○ ○ ○
16 → ○ ○[D9  ○ ○ ○ ○  5V]○ ○ ○ ○ ○ ○ ○ ○ ○ ○ ○  ← CS_ET, 5V
17 → ○ ○[D10 ○ ○ ○ ○ RST]○ ○ ○ ○ ○ ○ ○ ○ ○ ○ ○  ← CS_BT
18 → ○ ○[D11 ○ ○ ○ ○ GND]○ ○ ○ ○ ○ ○ ○ ○ ○ ○ ○  ← GND
19 → ○ ○[D12 ○ ○ ○ ○ VIN]○ ○ ○ ○ ○ ○ ○ ○ ○ ○ ○  ← SPI DO
     └─────────────────────────────────────────────────
     ┌─────────────────────────────────────────────────
     │ ZONE B: MAX31855 modules (rows 5-12, cols K-S)
     │ BT module: cols K-Q, rows 5-7
     │ ET module: cols K-Q, rows 9-11
     │ Caps soldered near each module
     └─────────────────────────────────────────────────
20 → ○ ○ ○ ○ ○ ○ ○ ○ ○ ○ ○ ○ ○ ○ ○ ○ ○ ○ ○
     ┌─────────────────────────────────────────────────
     │ ZONE C: OLED + thermocouple header pins
     │ (rows 21-25, cols A-G)
     │ 4-pin header for OLED wires (VCC GND SDA SCL)
     │ Screw terminal or pins for TC leads
     └─────────────────────────────────────────────────
21 → ○ ○ ○ ○ ○ ○ ○ ○ ○ ○ ○ ○ ○ ○ ○ ○ ○ ○ ○
22 → ○ ○ ○ ○ ○ ○ ○ ○ ○ ○ ○ ○ ○ ○ ○ ○ ○ ○ ○
23 → ○ ○ ○ ○ ○ ○ ○ ○ ○ ○ ○ ○ ○ ○ ○ ○ ○ ○ ○
24 → ○ ○ ○ ○ ○ ○ ○ ○ ○ ○ ○ ○ ○ ○ ○ ○ ○ ○ ○
25 → ○ ○ ○ ○ ○ ○ ○ ○ ○ ○ ○ ○ ○ ○ ○ ○ ○ ○ ○
26 → ○ ○ ○ ○ ○ ○ ○ ○ ○ ○ ○ ○ ○ ○ ○ ○ ○ ○ ○
27 → ○ ○ ○ ○ ○ ○ ○ ○ ○ ○ ○ ○ ○ ○ ○ ○ ○ ○ ○
```

### Assembly Notes

1. **Arduino Nano** — Insert pin headers into rows 5-19, columns C and H. USB-C faces the board edge (row 5). The Nano straddles 6 strips.

2. **MAX31855 Modules** — Place to the right of the Nano in Zone B. Break copper strips between the Nano and modules to avoid shorts. Each module needs VCC, GND, SCK, DO, CS connected back to the Nano plus TC+/TC- for thermocouple wires.

3. **Decoupling Caps** — Solder C1 and C2 directly across VCC/GND pins of each MAX31855, as close as physically possible.

4. **OLED Header** — 4-pin male header in Zone C for connecting flying leads to the panel-mounted OLED.

5. **Strip Breaks** — Cut copper strips between:
   - Nano left pins and right pins (between cols C-H under the Nano body)
   - Between Zone A and Zone B where different signals share a strip
   - Anywhere two signals that shouldn't connect share a strip row

6. **Power Distribution** — Run a 5V bus and GND bus along available strip rows. Bridge from Nano 5V (row 16, col H) to the bus, and from Nano GND (row 18, col H) to the bus.

7. **SPI Bus** — D13/SCK (row 5, col H) needs to reach both MAX31855 SCK pins. D12/DO (row 19, col C) needs to reach both MAX31855 DO pins. Use wire links on the underside or jumper wires on top.

8. **Thermocouple Leads** — Bare tinned wire from K-type probes connects directly to MAX31855 screw terminals. **Red wire is NEGATIVE** — connect to TC-.

## Thermocouple Assignment

| Probe | Size | Channel | Pin | Position |
|---|---|---|-----|---|
| BT (Bean Temp) | 35mm/2.5mm | D10 | CS_BT | Inside drum, in bean mass |
| ET (Exhaust Temp) | 50mm/3.0mm | D9 | CS_ET | Exhaust path, 10-15cm from drum |

## Probe Placement

```
                    ┌─────────────────────────────────┐
                    │           EXHAUST               │
                    │             ▲                   │
                    │      ┌──────┴──────┐           │
                    │      │             │           │
                    │      │   ◄─────────│── ET      │ 50mm/3.0mm probe
                    │      │             │           │ (in exhaust flow)
                    │      │    DRUM     │           │
                    │      │             │           │
                    │      │   ●●●●●     │           │
                    │      │   ●●●●● ◄───│── BT      │ 35mm/2.5mm probe
                    │      │   ●●●●●     │           │ (in bean mass)
                    │      │             │           │
                    │      └──────┬──────┘           │
                    │             │                   │
                    │      ┌──────┴──────┐           │
                    │      │   BURNER    │           │
                    │      └─────────────┘           │
                    └─────────────────────────────────┘
```

## Power Budget

| Component | Current Draw |
|---|---|
| Arduino Nano | ~19mA (idle) |
| MAX31855 × 2 | ~1.5mA total |
| 1.3" OLED SH1106 | ~25mA |
| **Total** | **~48mA** |

USB from RPi 4 supplies 500mA minimum — more than sufficient.

## WireViz Diagram

The machine-generated wiring diagram is at:
- `docs/wiring.png` — PNG image
- `docs/wiring.svg` — Scalable vector
- `docs/wiring.html` — Interactive HTML with BOM

Generate from YAML source:
```bash
cd ~/projects/Milk-Depot-Coffee-Roaster
wireviz docs/wiring.yml
```

## Safety Notes

1. **Thermocouple Polarity**: Red wire is **negative** on K-type thermocouples. Reversing polarity causes readings to decrease with increasing temperature.
2. **Heat Protection**: Keep electronics and connectors away from heat sources. Only probe tips enter hot zones.
3. **Cable Routing**: Route thermocouple leads away from power cables to minimise interference.
4. **Decoupling**: 100nF caps on each MAX31855 are essential for stable readings.
5. **Grounding**: All GND connections should meet at a single point (star ground) to reduce noise.

---

*Version 2.0 — Updated 16 March 2026 for 2-channel Arduino Nano design*
*Previous: v1.0 (3-channel Arduino UNO R3, December 2024)*

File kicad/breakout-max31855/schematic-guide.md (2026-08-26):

# MD-TC-BRK v1.0 — Schematic Drawing Guide

Reference for drawing the MAX31855 thermocouple breakout schematic from scratch in KiCad 10 Eeschema. Derived from SparkFun DEV-13266 topology, forked for the Milk Depot Coffee Roaster project.

Keep this open alongside Eeschema while drawing. Use the SparkFun reference in `eagle-source/SparkFun_Thermocouple_Breakout.sch` (open in Eagle) or the PDF in `~/tools/kicad-coffee-roaster/docs/reference-designs/sparkfun-max31855k/` as a visual template.

## Design intent (locked session 2)

- Fork of SparkFun DEV-13266, released under CC-BY-SA 4.0
- MAX31855KASA+ genuine Maxim (not MAX31855K from Eagle origin)
- DG127-5.08-02P screw terminal (not SparkFun's PCB pad pattern)
- 0805 passives throughout (upsized from SparkFun 0603)
- DNP footprints for EMI/surge mitigation (populate only if burner EMI shows up at bring-up)
- Chassis-bond footprint with default hard-bond jumper + soft-bond DNP option

## Component reference table

All symbols and footprints use KiCad 10 stock libraries unless flagged otherwise.

| Ref | Value | Symbol (`lib:name`) | Footprint (`lib:name`) | DNP | Notes |
|---|---|---|---|:---:|---|
| **U1** | MAX31855KASA+ | `Sensor_Temperature:MAX31855KASA` | `Package_SO:SOIC-8_3.9x4.9mm_P1.27mm` | | MPN field = `MAX31855KASA+`. Pin map: 1=GND, 2=T−, 3=T+, 4=VCC, 5=SCK, 6=CS, 7=SO(MISO), 8=NC |
| **C1** | 100 nF X7R 16 V | `Device:C` | `Capacitor_SMD:C_0805_2012Metric` | | +3V3 → GND decoupling, place within 5 mm of U1 pin 4 |
| **C2** | 10 nF X7R 50 V | `Device:C` | `Capacitor_SMD:C_0805_2012Metric` | | T+ ↔ T− differential filter, post-ferrite |
| **C3** | 1 nF X7R 50 V | `Device:C` | `Capacitor_SMD:C_0805_2012Metric` | **Y** | T+ ↔ GND common-mode (populate only if burner EMI) |
| **C4** | 1 nF X7R 50 V | `Device:C` | `Capacitor_SMD:C_0805_2012Metric` | **Y** | T− ↔ GND common-mode |
| **L1** | 470 Ω @ 100 MHz | `Device:FerriteBead` | `Inductor_SMD:L_0805_2012Metric` | | In-line on T+ between J1 and U1 |
| **L2** | 470 Ω @ 100 MHz | `Device:FerriteBead` | `Inductor_SMD:L_0805_2012Metric` | | In-line on T− |
| **R1** | 10 kΩ 1% | `Device:R` | `Resistor_SMD:R_0805_2012Metric` | | CS ↔ +3V3 pull-up (holds MAX31855 deselected at boot) |
| **D1** | SMAJ5.0CA (5 V bidi TVS) | `Device:D_TVS` | `Diode_SMD:D_SMA` | **Y** | T+ ↔ GND surge clamp |
| **D2** | SMAJ5.0CA (5 V bidi TVS) | `Device:D_TVS` | `Diode_SMD:D_SMA` | **Y** | T− ↔ GND surge clamp |
| **J1** | DG127-5.08-02P | `Connector:Screw_Terminal_01x02` | `Connector_Phoenix_MSTB:PhoenixContact_MSTBA_2,5_2-G-5,08_1x02_P5.08mm_Horizontal` | | **Verify DG127 pad/drill against MSTB footprint before fab** — if mismatch, create `milk-depot.pretty/DG127-5.08-02P.kicad_mod`. Pin 1 = T+, Pin 2 = T− |
| **JP1** | 1×06 male header 2.54 mm | `Connector_Generic:Conn_01x06` | `Connector_PinHeader_2.54mm:PinHeader_1x06_P2.54mm_Vertical` | | Pin 1=GND, 2=+3V3, 3=SCK, 4=MISO, 5=NC, 6=CS. Cable-compatible with SparkFun DEV-13266; we rename "VCC" → "3V3" on silkscreen to be voltage-explicit (prevents 5V mis-wiring on stripboard). |
| **TP1** | T+ post-filter | `Connector:TestPoint` | `TestPoint:TestPoint_Pad_D1.5mm` | | Multimeter probe pad |
| **TP2** | T− post-filter | `Connector:TestPoint` | `TestPoint:TestPoint_Pad_D1.5mm` | | |
| **MH1** | M3 mount / chassis | `Mechanical:MountingHole_Pad` | `MountingHole:MountingHole_3.2mm_M3_Pad` | | Net = `CHASSIS` |
| **SJ1** | Solder jumper (closed) | `Jumper:SolderJumper_2_Bridged` | `Jumper:SolderJumper-2_P1.3mm_Bridged_RoundedPad1.0x1.5mm` | | CHASSIS ↔ GND, default populated (hard bond) |
| **CY1** | 10 nF 250 V Y1 | `Device:C` | `Capacitor_SMD:C_0805_2012Metric` | **Y** | CHASSIS ↔ GND soft-bond cap (populate only if breaking SJ1) |
| **RB1** | 1 MΩ | `Device:R` | `Resistor_SMD:R_0805_2012Metric` | | CHASSIS ↔ GND bleed (keeps chassis at DC ground when only CY1 is present) |

**DNP note:** in KiCad 10, DNP is set per-symbol via Properties → *Do not populate* checkbox (or keystroke `V`). DNP symbols stay on the PCB but are flagged in BOM exports so the assembly house skips them.

## Net list — what wires where

U1 (MAX31855KASA) pin-by-pin connections:

```
U1 pin 1 (GND)   → GND
U1 pin 2 (T−)    → node after L2 → {C2 one side, C4 top, D2 anode, TP2, J1 pin 2}
U1 pin 3 (T+)    → node after L1 → {C2 other side, C3 top, D1 anode, TP1, J1 pin 1}
U1 pin 4 (Vcc)   → +3V3 → {C1 top, R1 top, JP1 pin 2}
U1 pin 5 (SCK)   → SCK → JP1 pin 3
U1 pin 6 (CS)    → CS  → {R1 bottom, JP1 pin 6}
U1 pin 7 (SO)    → MISO → JP1 pin 4
U1 pin 8 (NC)    → No-Connect flag (don't leave floating — ERC needs explicit NC)

C1, C3, C4, D1, D2 grounds → GND
JP1 pin 1 → GND
JP1 pin 5 → No-Connect flag

CHASSIS (MH1) → SJ1 (closed) → GND
CHASSIS → CY1 → GND  (DNP)
CHASSIS → RB1 → GND
```

**Filter topology reminder** (SparkFun LC, preserved):

```
J1 ─┬── L1(470Ω) ── TP1 ── U1 pin 3 (T+)
    │                  │
    │                  └── C2(10nF) ──┐
    │                                 │
    │                  ┌── C3(1nF DNP) ─ GND
    │                  │
    │                  └── D1(TVS DNP) ─ GND
    │
    └── L2(470Ω) ── TP2 ── U1 pin 2 (T−)
                       │
                       └── (C2 other side — shared)
                       │
                       ├── C4(1nF DNP) ─ GND
                       │
                       └── D2(TVS DNP) ─ GND
```

## Draw order

1. **Power rails first** — drop `Power:+3V3` and `Power:GND` symbols (voltage-explicit names prevent the 3V3-vs-5V mis-wiring risk on the stripboard). Add a `Power:PWR_FLAG` on each (kills `power_pin_not_driven` ERC errors at source).
2. **U1 centred** — place `Sensor_Temperature:MAX31855KASA` in the middle of the sheet. Label all 8 pins with their nets before adding anything else around it.
3. **Filter network to the left of U1** — J1 → L1/L2 → U1's T+/T−, with C2 bridging between them and C3/C4 pulling down to GND; TP1/TP2 on the post-filter nets.
4. **Protection cluster** — D1/D2 on the J1 side of the filter (clamps before the ferrites, protects upstream energy).
5. **VCC cluster above U1** — C1 decoupling, R1 CS pull-up.
6. **JP1 to the right of U1** — 6-pin header, connect one wire at a time to VCC/GND/SCK/MISO/CS. Drop an explicit `No Connect` marker on JP1 pin 5.
7. **Chassis bond cluster** — MH1 + SJ1 + CY1 + RB1 in a corner, net-label `CHASSIS`. SJ1 defaults populated (hard bond); CY1 is DNP for the soft-bond option.
8. **U1 pin 8** — drop a `No Connect` marker (KiCad ERC requires it for pins marked NC in the symbol, to confirm the intent).
9. **Title block** — KiCad Eeschema → File → Page Settings:
   - Title: `MAX31855 Thermocouple Breakout — MD-TC-BRK v1.0`
   - Date: today (e.g. `2026-04-21`)
   - Rev: `1.0`
   - Company: `Precept Systems (Pty) Ltd`
   - Comment 1: `Fork of SparkFun DEV-13266 — CC-BY-SA 4.0`
   - Comment 2: `MAX31855KASA+ / DG127-5.08-02P / 0805 / DNP EMI+TVS`
   - Comment 3: `Designer: Jason van Wyk — jason@precept.co.za`

## ERC verification checklist

After drawing, run ERC (Eeschema → Inspect → Electrical Rules Checker). Target: **0 errors, 0 warnings.** Expected issues if something's missed:

- [ ] All power nets have PWR_FLAG (VCC + GND) — otherwise `power_pin_not_driven`
- [ ] U1 pin 8 has explicit No Connect — otherwise `pin_not_connected`
- [ ] JP1 pin 5 has explicit No Connect — otherwise `pin_not_connected`
- [ ] All components have footprints assigned — otherwise `footprint_link_issues`
- [ ] All components have MPN (custom property) for BOM — check via Edit Symbol Fields (Ctrl-E from Eeschema top menu)
- [ ] No dangling wires (look for green dots)
- [ ] All net labels match exactly (CS, SCK, MISO, VCC, GND, CHASSIS — no typos)

Command-line ERC (fastest iteration):

```bash
cd /home/jason/projects/Milk-Depot-Coffee-Roaster/kicad/breakout-max31855
kicad-cli sch erc --output erc.txt breakout-max31855.kicad_sch
```

## BOM export

Once ERC-clean, export BOM for cross-check against `docs/BOM.md`:

```bash
kicad-cli sch export bom \
  --fields "Reference,Value,Footprint,MPN,DNP" \
  --group-by Value,Footprint \
  --preset "CSV" \
  --output breakout-max31855-bom.csv \
  breakout-max31855.kicad_sch
```

## Silkscreen + layout notes (for later, not schematic)

These go on the PCB, not the schematic:

- **Pin 1 dot** on U1
- **Red = NEGATIVE** warning next to J1
- **+** / **−** marked on J1 pin 1 / pin 2 silkscreen
- **3V3** label on JP1 pin 2 (replaces SparkFun's "VCC" label — voltage-explicit, eliminates the need for a separate "3.3V ONLY" warning)
- Board ID: `MD-TC-BRK v1.0 / CC-BY-SA 4.0 / fork of SparkFun DEV-13266`
- Attribution: `derived from SparkFun DEV-13266`

## References

- **SparkFun upstream (Eagle):** `eagle-source/SparkFun_Thermocouple_Breakout.sch`
- **Maxim datasheet:** `../datasheets/max31855.pdf`
- **Project design spec:** `../../docs/planning/` (architecture decisions)
- **Degson DG127 datasheet:** confirm pad/drill dimensions at <https://www.degson.com/product/DG127> before fab
- **KiCad 10 symbol libs:** `/usr/share/kicad/symbols/`
- **KiCad 10 footprint libs:** `/usr/share/kicad/footprints/`

## Design spec cross-reference

Full electrical + mechanical spec lives in the tool-repo memory: `~/.claude/projects/-home-jason-tools-kicad-coffee-roaster/memory/design-spec-v2.md`. Any deviation from this guide must go back to update that memory.

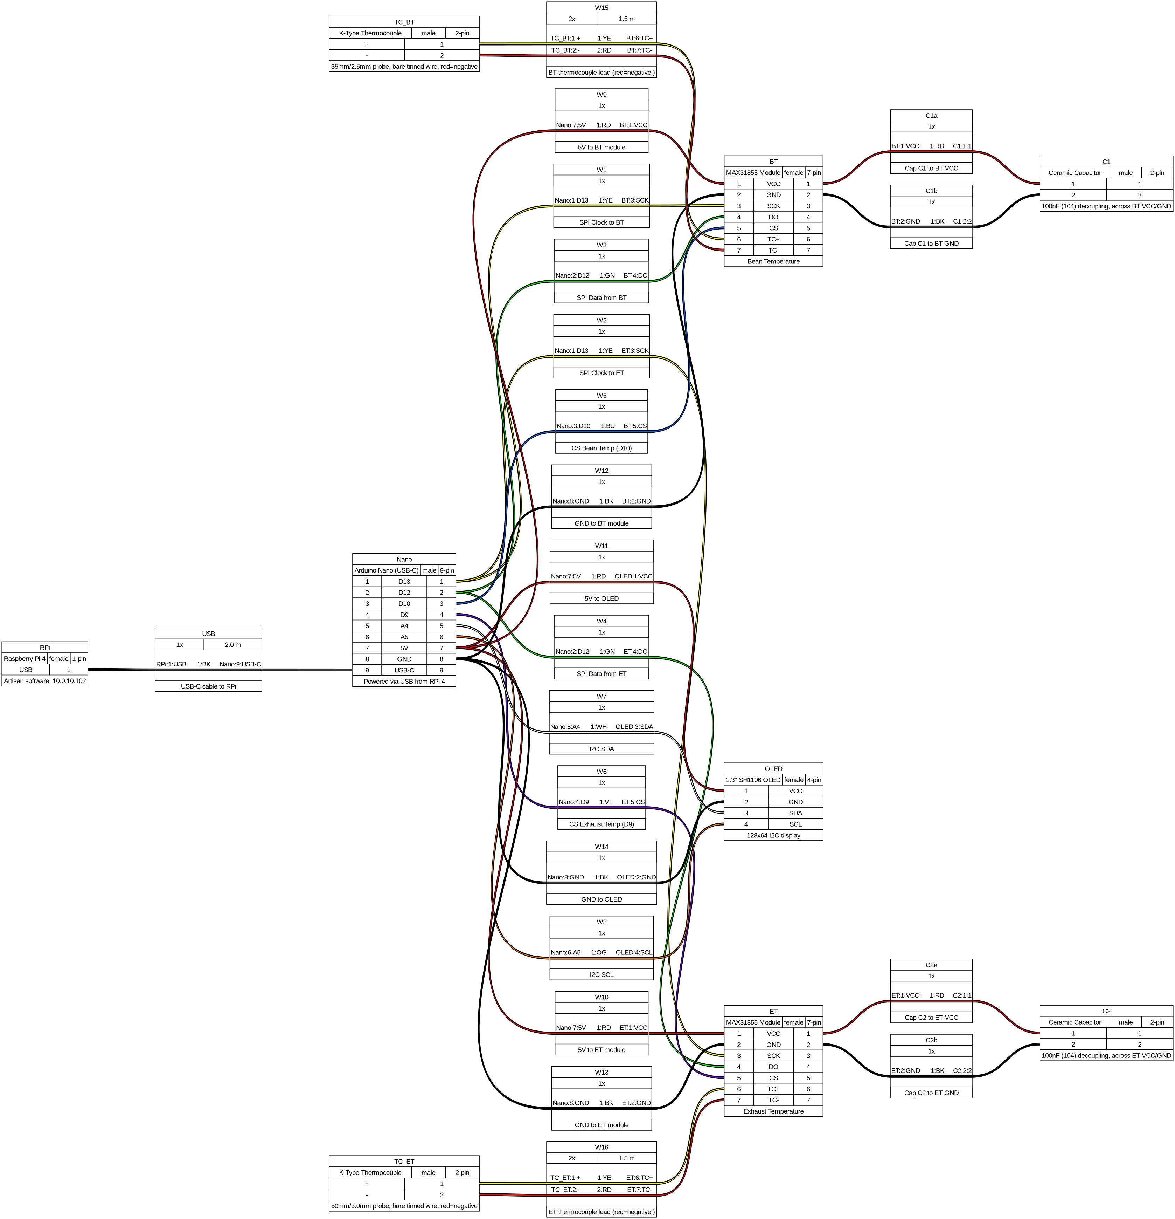
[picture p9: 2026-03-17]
docs/wiring.png

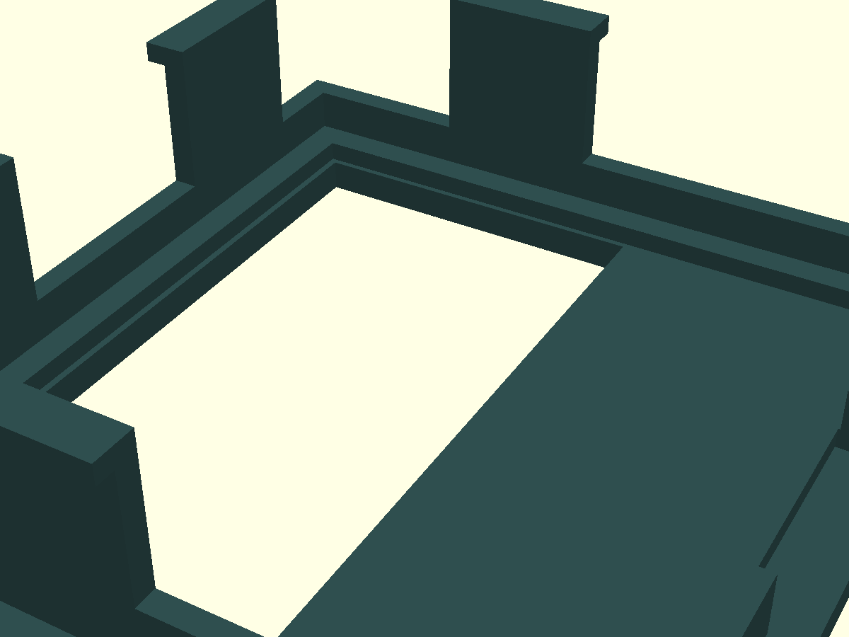
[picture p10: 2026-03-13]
3d-prints/oled-bezel-side.png

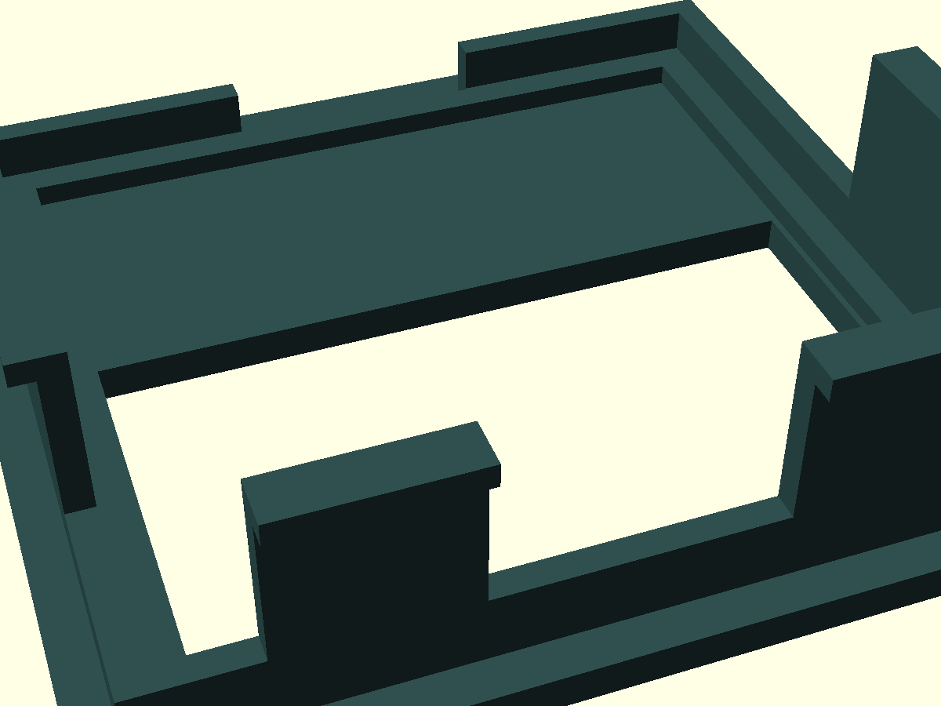
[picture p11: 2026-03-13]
3d-prints/oled-bezel-facedown.png

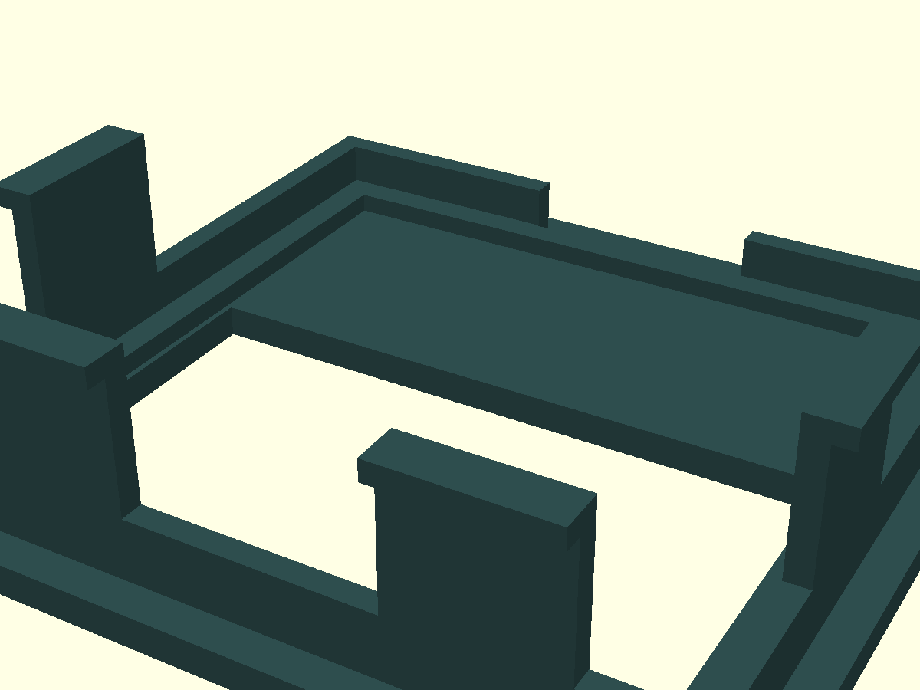
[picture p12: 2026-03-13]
3d-prints/oled-bezel-preview.png

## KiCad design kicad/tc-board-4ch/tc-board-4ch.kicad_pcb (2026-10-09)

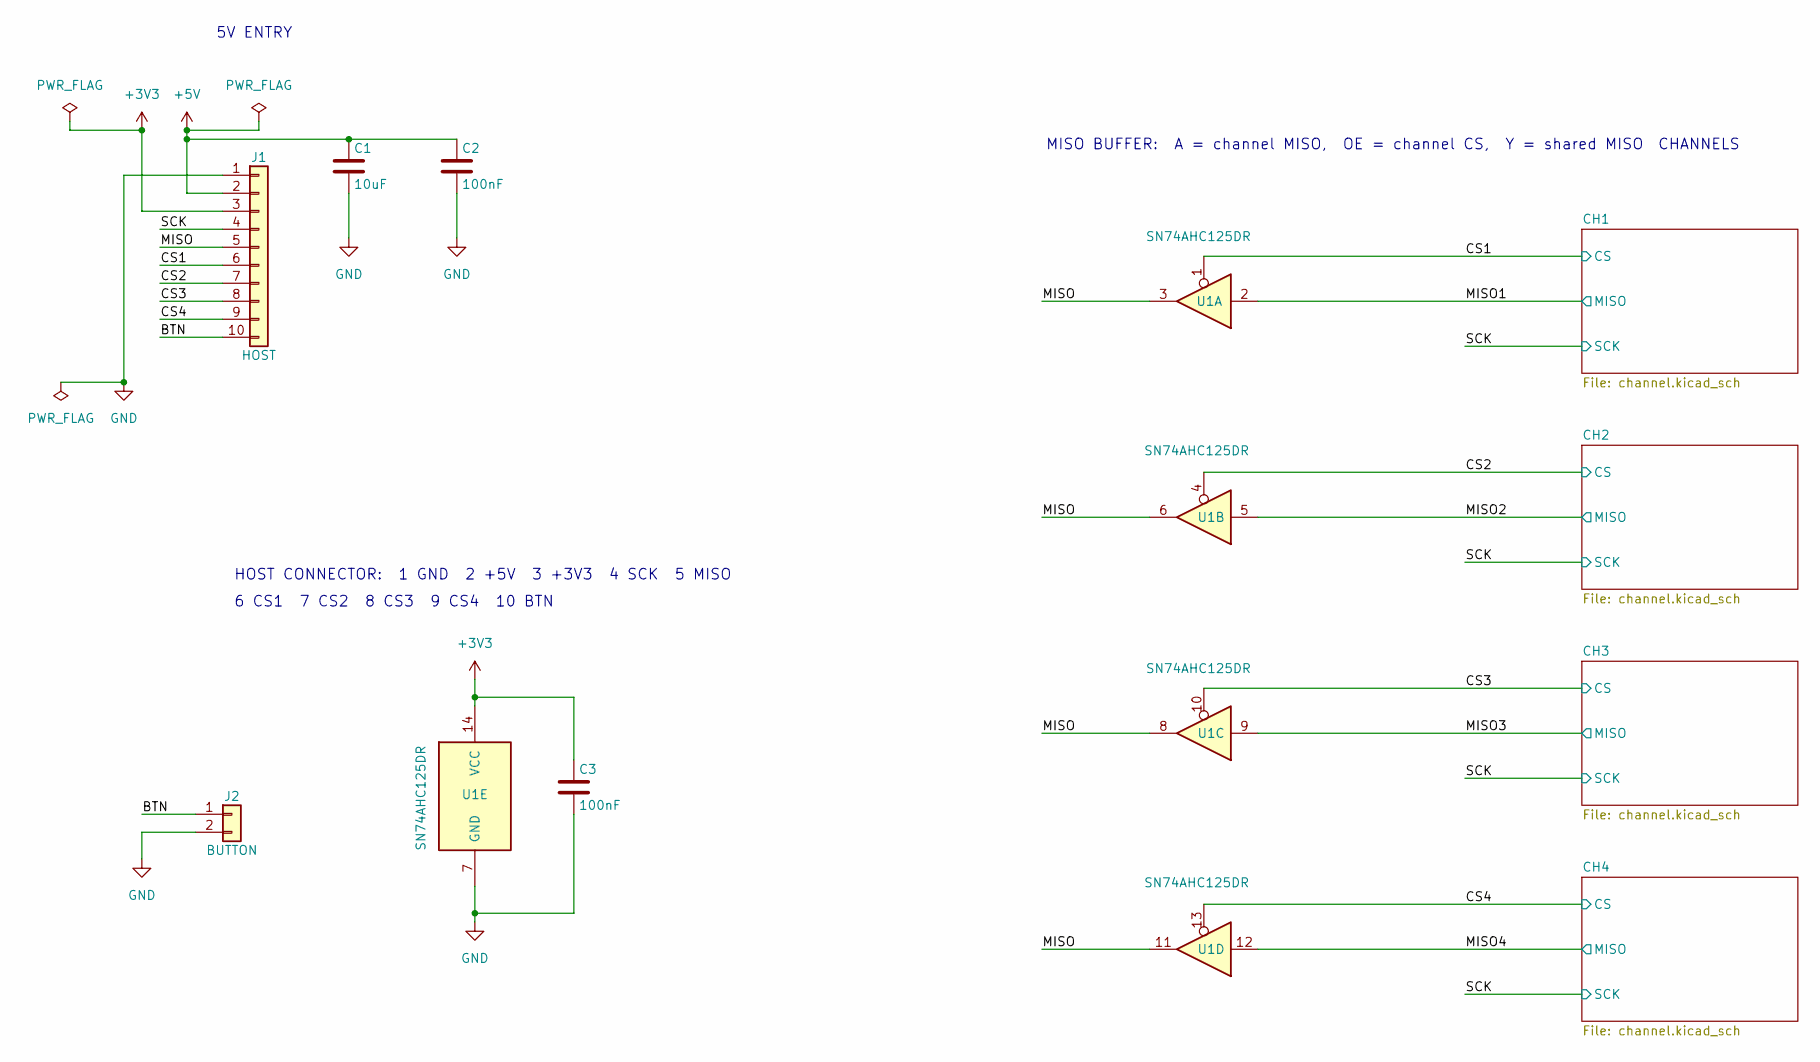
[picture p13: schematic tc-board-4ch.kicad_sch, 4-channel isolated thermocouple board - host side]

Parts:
C1: 10uF; C_0805_2012Metric; MPN GRM21BR61C106KE15L
C2, C3: 100nF; C_0805_2012Metric; MPN CL21B104KBCNNNC
J1: HOST; PinHeader_1x10_P2.54mm_Vertical
J2: BUTTON; JST_PH_B2B-PH-K_1x02_P2.00mm_Vertical; MPN B2B-PH-K-S
U1: SN74AHC125DR; SOIC-14_3.9x8.7mm_P1.27mm; MPN SN74AHC125DR

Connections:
+3V3: C3.1, J1.3, U1.14 (VCC); also elsewhere on the board
+5V: C1.1, C2.1, J1.2; also elsewhere on the board
/BTN: J1.10, J2.1
/CS1: J1.6, U1.1; also elsewhere on the board
/CS2: J1.7, U1.4; also elsewhere on the board
/CS3: J1.8, U1.10; also elsewhere on the board
/CS4: J1.9, U1.13; also elsewhere on the board
/MISO: J1.5, U1.3, U1.6, U1.8, U1.11
/MISO1: U1.2; also elsewhere on the board
/MISO2: U1.5; also elsewhere on the board
/MISO3: U1.9; also elsewhere on the board
/MISO4: U1.12; also elsewhere on the board
/SCK: J1.4; also elsewhere on the board
GND: C1.2, C2.2, C3.2, J1.1, J2.2, U1.7 (GND); also elsewhere on the board

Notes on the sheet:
CHANNELS
HOST CONNECTOR: 1 GND 2 +5V 3 +3V3 4 SCK 5 MISO
6 CS1 7 CS2 8 CS3 9 CS4 10 BTN
5V ENTRY
MISO BUFFER: A = channel MISO, OE = channel CS, Y = shared MISO

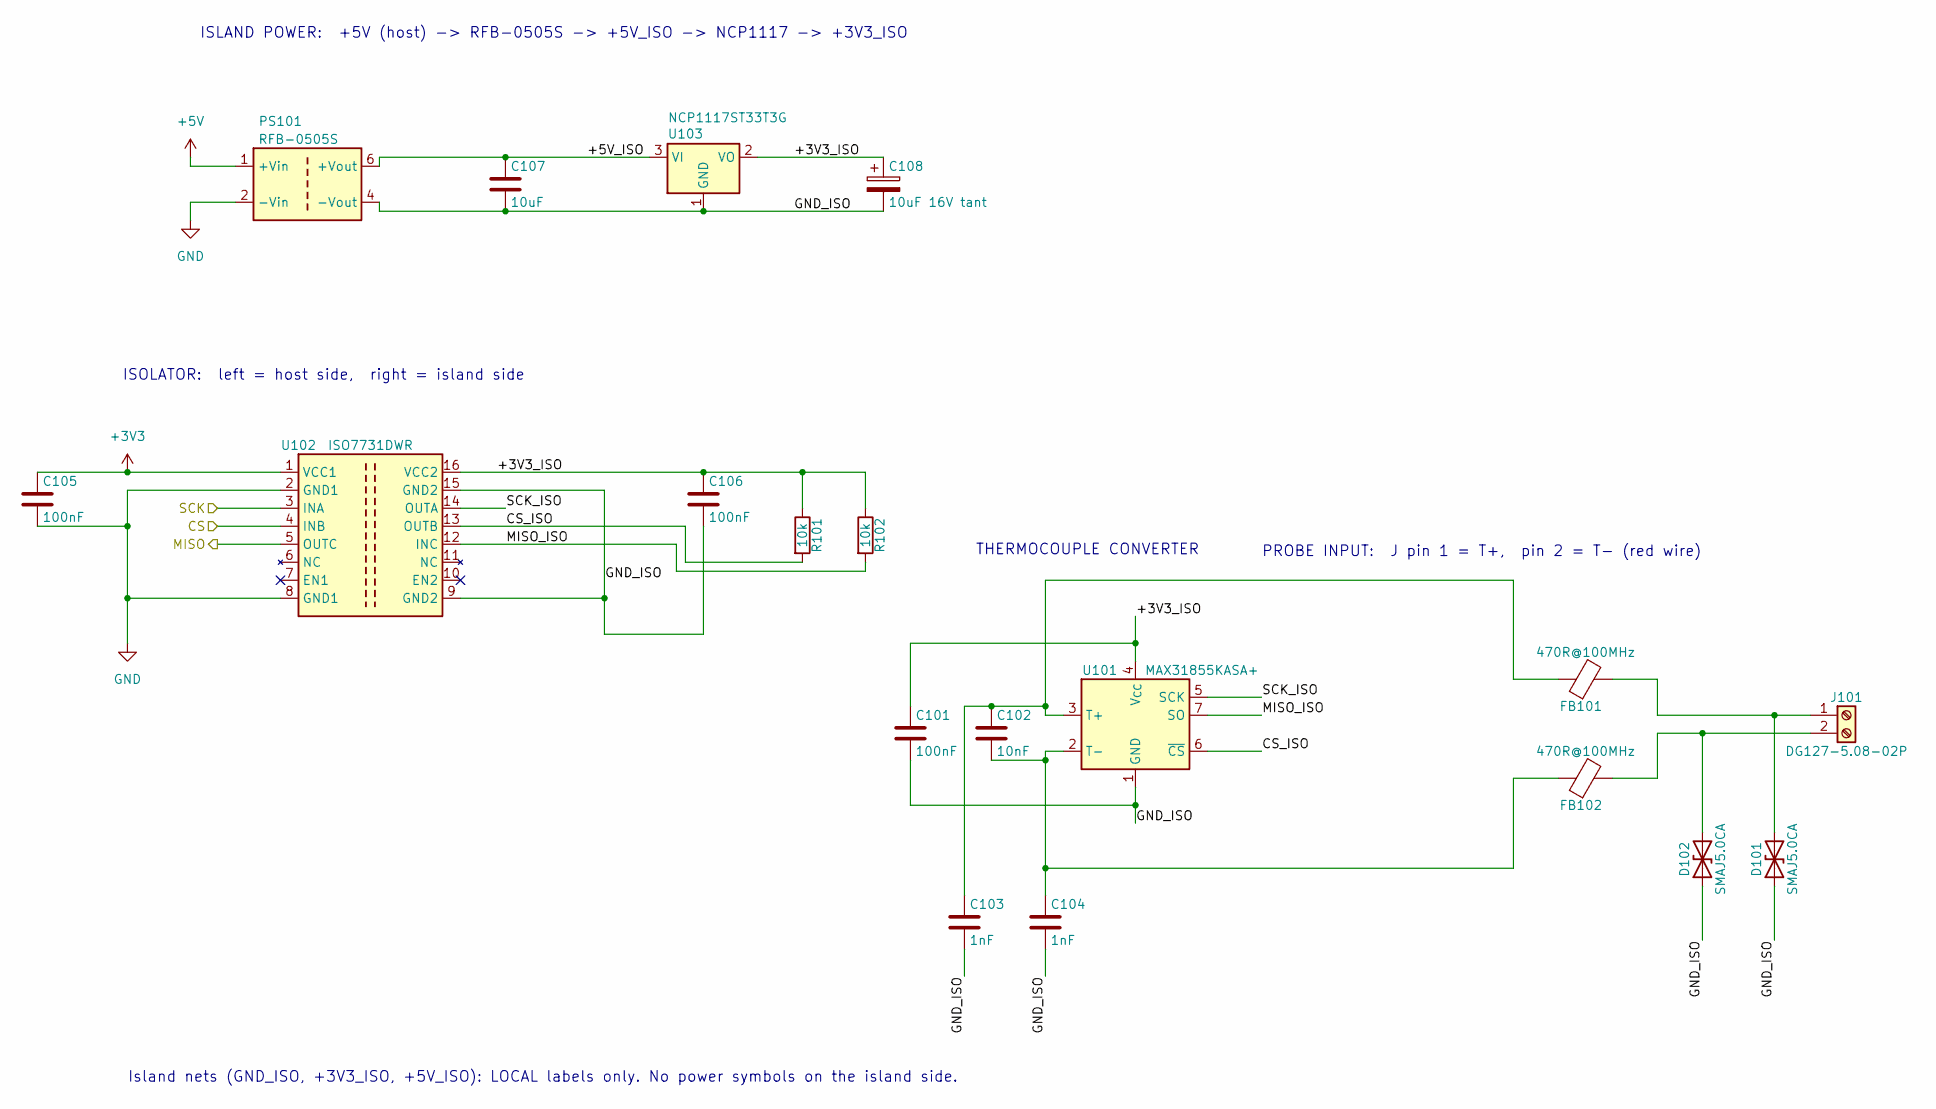
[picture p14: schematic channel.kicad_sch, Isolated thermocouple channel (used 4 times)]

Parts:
C101, C105, C106: 100nF; C_0805_2012Metric; MPN CL21B104KBCNNNC
C102: 10nF; C_0805_2012Metric; MPN CL21B103KBANNNC
C103, C104: 1nF; C_0805_2012Metric; MPN CL21B102KBANNNC
C107: 10uF; C_0805_2012Metric; MPN GRM21BR61C106KE15L
C108: 10uF 16V tant; CP_EIA-3528-21_Kemet-B; MPN TPSB106K016R0800
D101, D102: SMAJ5.0CA; D_SMA; MPN SMAJ5.0CA-13-F
FB101, FB102: 470R@100MHz; L_0805_2012Metric; MPN BLM21AG471SN1D
J101: DG127-5.08-02P; Degson_DG127-5.08-02P_1x02_P5.08mm_Horizontal; MPN DG127-5.08-02P-14
PS101: RFB-0505S; Converter_DCDC_TRACO_TMA-05xxS_12xxS_Single_THT; MPN RFB-0505S
R101, R102: 10k; R_0805_2012Metric; MPN RC0805FR-0710KL
U101: MAX31855KASA+; SOIC-8_3.9x4.9mm_P1.27mm; MPN MAX31855KASA+
U102: ISO7731DWR; SOIC-16W_7.5x10.3mm_P1.27mm; MPN ISO7731DWR
U103: NCP1117ST33T3G; SOT-223-3_TabPin2; MPN NCP1117ST33T3G

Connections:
+3V3: C105.1, U102.1 (VCC1); also elsewhere on the board
+5V: PS101.1 (+Vin); also elsewhere on the board
/CH1/+3V3_ISO: C101.1, C106.1, C108.1, R101.1, R102.1, U101.4 (V_{CC}), U102.16 (VCC2), U103.2 (VO)
/CH1/+5V_ISO: C107.1, PS101.6 (+Vout), U103.3 (VI)
/CH1/CS_ISO: R101.2, U101.6 (~CS), U102.13 (OUTB)
/CH1/GND_ISO: C101.2, C103.2, C104.2, C106.2, C107.2, C108.2, D101.1 (A1), D102.1 (A1), PS101.4 (-Vout), U101.1 (GND), U102.9 (GND2), U102.15 (GND2), U103.1 (GND)
/CH1/MISO_ISO: R102.2, U101.7 (SO), U102.12 (INC)
/CH1/SCK_ISO: U101.5 (SCK), U102.14 (OUTA)
/CS1: U102.4 (INB); also elsewhere on the board
/MISO1: U102.5 (OUTC); also elsewhere on the board
/SCK: U102.3 (INA); also elsewhere on the board
GND: C105.2, PS101.2 (-Vin), U102.2 (GND1), U102.8 (GND1); also elsewhere on the board
unnamed: D101.2 (A2), FB101.2, J101.1
unnamed: D102.2 (A2), FB102.2, J101.2
unnamed: C102.1, C103.1, FB101.1, U101.3 (T+)
unnamed: C102.2, C104.1, FB102.1, U101.2 (T-)

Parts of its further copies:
C201, C205, C206, C301, C305, C306, C401, C405, C406: 100nF; C_0805_2012Metric; MPN CL21B104KBCNNNC
C202, C302, C402: 10nF; C_0805_2012Metric; MPN CL21B103KBANNNC
C203, C204, C303, C304, C403, C404: 1nF; C_0805_2012Metric; MPN CL21B102KBANNNC
C207, C307, C407: 10uF; C_0805_2012Metric; MPN GRM21BR61C106KE15L
C208, C308, C408: 10uF 16V tant; CP_EIA-3528-21_Kemet-B; MPN TPSB106K016R0800
D201, D202, D301, D302, D401, D402: SMAJ5.0CA; D_SMA; MPN SMAJ5.0CA-13-F
FB201, FB202, FB301, FB302, FB401, FB402: 470R@100MHz; L_0805_2012Metric; MPN BLM21AG471SN1D
J201, J301, J401: DG127-5.08-02P; Degson_DG127-5.08-02P_1x02_P5.08mm_Horizontal; MPN DG127-5.08-02P-14
PS201, PS301, PS401: RFB-0505S; Converter_DCDC_TRACO_TMA-05xxS_12xxS_Single_THT; MPN RFB-0505S
R201, R202, R301, R302, R401, R402: 10k; R_0805_2012Metric; MPN RC0805FR-0710KL
U201, U301, U401: MAX31855KASA+; SOIC-8_3.9x4.9mm_P1.27mm; MPN MAX31855KASA+
U202, U302, U402: ISO7731DWR; SOIC-16W_7.5x10.3mm_P1.27mm; MPN ISO7731DWR
U203, U303, U403: NCP1117ST33T3G; SOT-223-3_TabPin2; MPN NCP1117ST33T3G

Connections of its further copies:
+3V3: C205.1, C305.1, C405.1, U202.1 (VCC1), U302.1 (VCC1), U402.1 (VCC1); also elsewhere on the board
+5V: PS201.1 (+Vin), PS301.1 (+Vin), PS401.1 (+Vin); also elsewhere on the board
/CH2/+3V3_ISO: C201.1, C206.1, C208.1, R201.1, R202.1, U201.4 (V_{CC}), U202.16 (VCC2), U203.2 (VO)
/CH2/+5V_ISO: C207.1, PS201.6 (+Vout), U203.3 (VI)
/CH2/CS_ISO: R201.2, U201.6 (~CS), U202.13 (OUTB)
/CH2/GND_ISO: C201.2, C203.2, C204.2, C206.2, C207.2, C208.2, D201.1 (A1), D202.1 (A1), PS201.4 (-Vout), U201.1 (GND), U202.9 (GND2), U202.15 (GND2), U203.1 (GND)
/CH2/MISO_ISO: R202.2, U201.7 (SO), U202.12 (INC)
/CH2/SCK_ISO: U201.5 (SCK), U202.14 (OUTA)
/CH3/+3V3_ISO: C301.1, C306.1, C308.1, R301.1, R302.1, U301.4 (V_{CC}), U302.16 (VCC2), U303.2 (VO)
/CH3/+5V_ISO: C307.1, PS301.6 (+Vout), U303.3 (VI)
/CH3/CS_ISO: R301.2, U301.6 (~CS), U302.13 (OUTB)
/CH3/GND_ISO: C301.2, C303.2, C304.2, C306.2, C307.2, C308.2, D301.1 (A1), D302.1 (A1), PS301.4 (-Vout), U301.1 (GND), U302.9 (GND2), U302.15 (GND2), U303.1 (GND)
/CH3/MISO_ISO: R302.2, U301.7 (SO), U302.12 (INC)
/CH3/SCK_ISO: U301.5 (SCK), U302.14 (OUTA)
/CH4/+3V3_ISO: C401.1, C406.1, C408.1, R401.1, R402.1, U401.4 (V_{CC}), U402.16 (VCC2), U403.2 (VO)
/CH4/+5V_ISO: C407.1, PS401.6 (+Vout), U403.3 (VI)
/CH4/CS_ISO: R401.2, U401.6 (~CS), U402.13 (OUTB)
/CH4/GND_ISO: C401.2, C403.2, C404.2, C406.2, C407.2, C408.2, D401.1 (A1), D402.1 (A1), PS401.4 (-Vout), U401.1 (GND), U402.9 (GND2), U402.15 (GND2), U403.1 (GND)
/CH4/MISO_ISO: R402.2, U401.7 (SO), U402.12 (INC)
/CH4/SCK_ISO: U401.5 (SCK), U402.14 (OUTA)
/CS2: U202.4 (INB); also elsewhere on the board
/CS3: U302.4 (INB); also elsewhere on the board
/CS4: U402.4 (INB); also elsewhere on the board
/MISO2: U202.5 (OUTC); also elsewhere on the board
/MISO3: U302.5 (OUTC); also elsewhere on the board
/MISO4: U402.5 (OUTC); also elsewhere on the board
/SCK: U202.3 (INA), U302.3 (INA), U402.3 (INA); also elsewhere on the board
GND: C205.2, C305.2, C405.2, PS201.2 (-Vin), PS301.2 (-Vin), PS401.2 (-Vin), U202.2 (GND1), U202.8 (GND1), U302.2 (GND1), U302.8 (GND1), U402.2 (GND1), U402.8 (GND1); also elsewhere on the board
unnamed: D201.2 (A2), FB201.2, J201.1
unnamed: D202.2 (A2), FB202.2, J201.2
unnamed: D301.2 (A2), FB301.2, J301.1
unnamed: D302.2 (A2), FB302.2, J301.2
unnamed: D401.2 (A2), FB401.2, J401.1
unnamed: D402.2 (A2), FB402.2, J401.2
unnamed: C202.1, C203.1, FB201.1, U201.3 (T+)
unnamed: C202.2, C204.1, FB202.1, U201.2 (T-)
unnamed: C302.1, C303.1, FB301.1, U301.3 (T+)
unnamed: C302.2, C304.1, FB302.1, U301.2 (T-)
unnamed: C402.1, C403.1, FB401.1, U401.3 (T+)
unnamed: C402.2, C404.1, FB402.1, U401.2 (T-)

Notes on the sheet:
ISOLATOR: left = host side, right = island side
Island nets (GND_ISO, +3V3_ISO, +5V_ISO): LOCAL labels only. No power symbols on the island side.
ISLAND POWER: +5V (host) -> RFB-0505S -> +5V_ISO -> NCP1117 -> +3V3_ISO
THERMOCOUPLE CONVERTER
PROBE INPUT: J pin 1 = T+, pin 2 = T- (red wire)

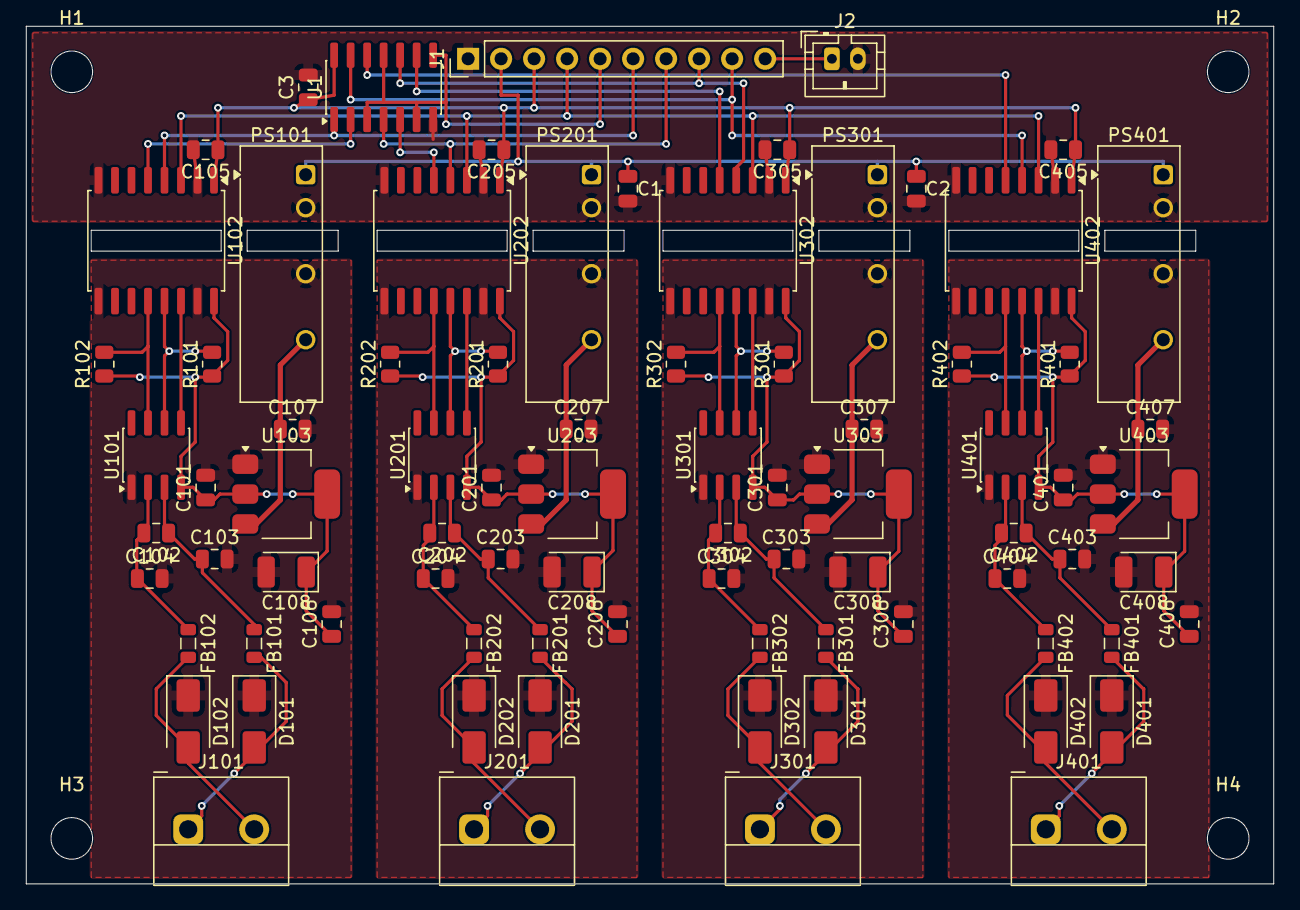
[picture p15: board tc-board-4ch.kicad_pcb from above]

Board: 2 copper layers, 96.0 x 66.0 mm, 86 parts (0 on the bottom side), 54 nets.

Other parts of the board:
H1, H2, H3, H4: MountingHole_3.2mm_M3

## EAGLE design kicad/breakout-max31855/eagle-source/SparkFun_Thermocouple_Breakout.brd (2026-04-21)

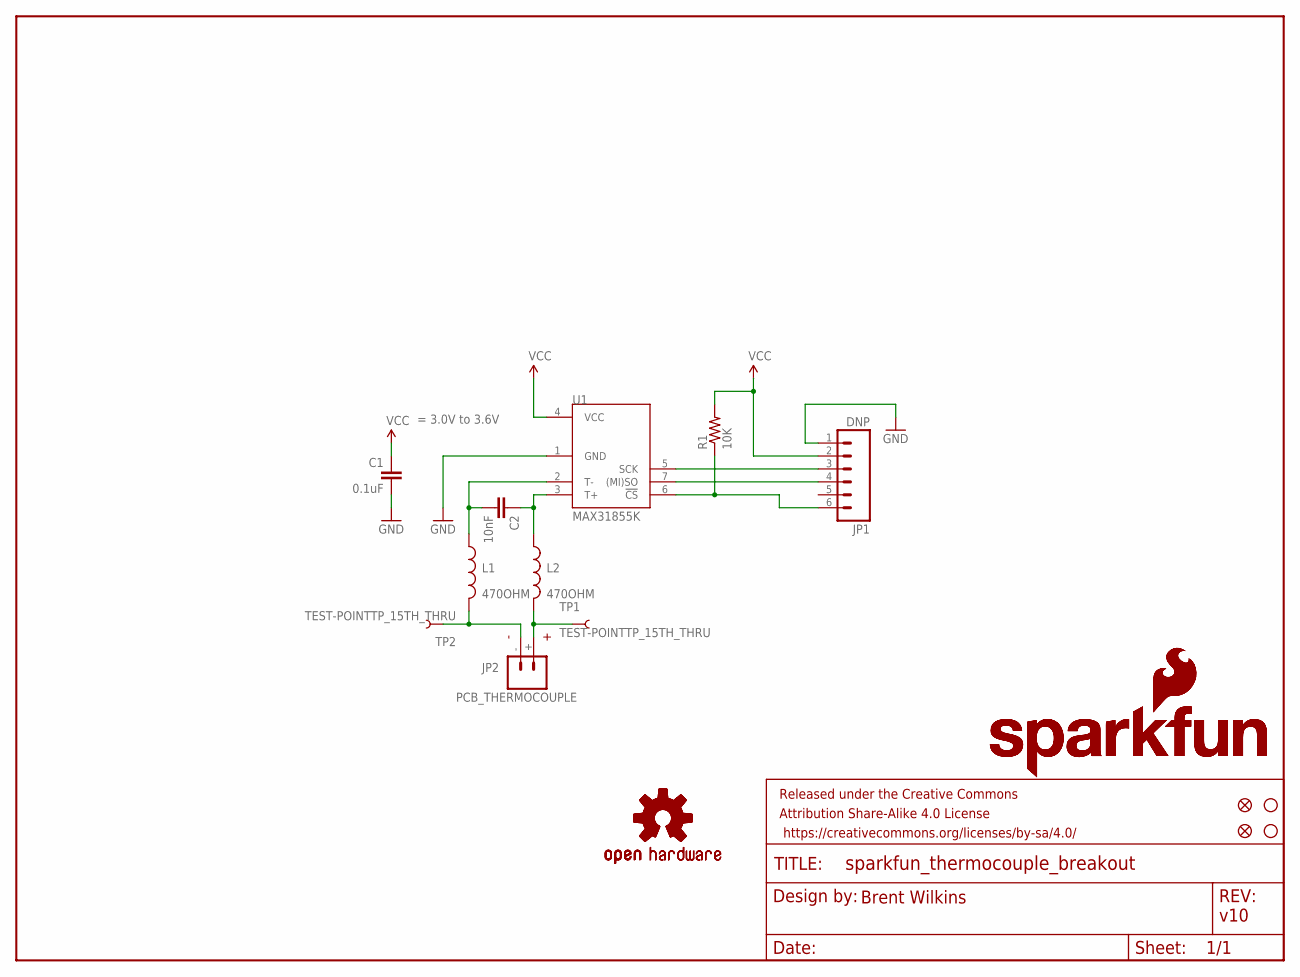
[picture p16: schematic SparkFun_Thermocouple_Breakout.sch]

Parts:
C1: 0.1uF; 0603-CAP
C2: 10nF; 0603-CAP
FID1, FID2: FIDUCIAL1X2; FIDUCIAL-1X2
FRAME1: >VERSION; CREATIVE_COMMONS
JP1: DNP; 1X06
JP2: PCB_THERMOCOUPLE; PCC-SMP
L1, L2: 470OHM; 0603
LOGO1, LOGO4: OSHW-LOGOS; OSHW-LOGO-S
LOGO2, LOGO3: SFE_LOGO_NAME_FLAME.1_INCH; SFE_LOGO_NAME_FLAME_.1
R1: 10K; 0603-RES
STANDOFF1, STANDOFF4: STAND-OFF
TP1, TP2: TEST-POINTTP_15TH_THRU; TP_15TH
U1: MAX31855K; SOIC8

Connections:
GND: C1.2, JP1.1, U1.1 (GND)
unnamed: JP1.3, U1.5 (SCK)
unnamed: JP1.4, U1.7 ((MI)SO)
unnamed: C2.2, L1.1, U1.2 (T-)
unnamed: JP2.+, L2.2, TP1.P$1
unnamed: JP2.-, L1.2, TP2.P$1
unnamed: C2.1, L2.1, U1.3 (T+)
unnamed: JP1.6, R1.1, U1.6 (!CS)
VCC: C1.1, JP1.2, R1.2, U1.4 (VCC)

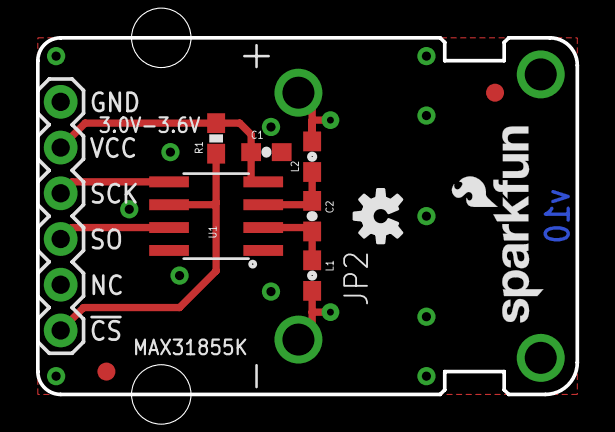
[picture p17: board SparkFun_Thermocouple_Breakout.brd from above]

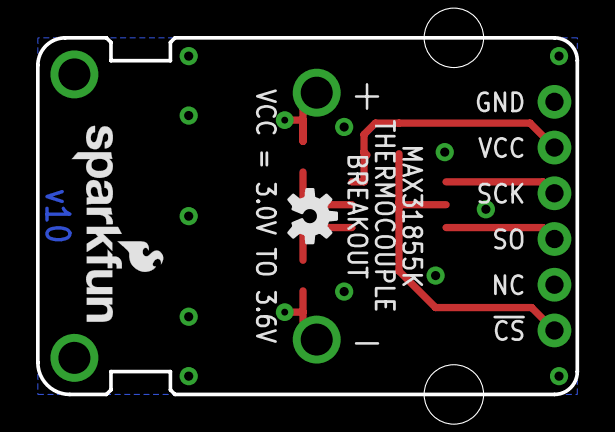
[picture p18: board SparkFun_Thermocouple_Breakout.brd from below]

Board: 2 copper layers, 30.0 x 19.8 mm, 19 parts (2 on the bottom side), 9 nets.

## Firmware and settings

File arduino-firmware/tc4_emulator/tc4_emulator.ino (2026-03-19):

/*
 * TC4 Protocol Emulator for Artisan - 2-Channel Thermocouple Version
 *
 * Milk Depot Coffee Roaster - Production Firmware
 * Target: Arduino Nano (ATmega328P, USB-C variant)
 *
 * Emulates the TC4 serial protocol for Artisan roasting software.
 * Reads 2 K-type thermocouples via MAX31855 amplifier modules (SPI).
 *
 * Channels:
 *   - Channel 1 (ET): Exhaust/Environment Temperature
 *   - Channel 2 (BT): Bean Temperature
 *   - Channel 3: Unused (reports 0)
 *   - Channel 4: Unused (reports 0)
 *
 * Artisan Configuration:
 *   - Device: ArduinoTC4 (for channels 1+2)
 *   - Port: /dev/ttyACM0 or /dev/ttyUSB0
 *   - Baud: 115200
 *
 * Hardware:
 *   - Arduino Nano (USB-C)
 *   - 2x MAX31855 thermocouple amplifier modules
 *   - 2x Custom K-type probes (GPA Trading, 316L SS)
 *     - BT: 35mm/2.5mm probe
 *     - ET: 50mm/3.0mm probe
 *   - 1.3" SH1106 OLED display (I2C)
 *   - 100nF ceramic decoupling caps on each MAX31855
 *
 * Author: Jason
 * Repository: https://github.com/jasonvanwyk/Milk-Depot-Coffee-Roaster
 */

#include <SPI.h>
#include <Adafruit_MAX31855.h>
#include <Wire.h>
#include <Adafruit_GFX.h>
#include <Adafruit_SH110X.h>

// ============================================================================
// CONFIGURATION
// ============================================================================

const unsigned long BAUD_RATE = 115200;

// SPI Pin Definitions (shared bus)
const int PIN_SCK  = 13;   // SPI Clock (shared)
const int PIN_MISO = 12;   // SPI Data Out (shared)

// Chip Select pins (active low)
const int PIN_CS_ET = 10;  // CS for Exhaust Temperature (Channel 1)
const int PIN_CS_BT = 9;   // CS for Bean Temperature (Channel 2)

// OLED Display (1.3" SH1106, I2C)
const int OLED_WIDTH = 128;
const int OLED_HEIGHT = 64;
const int OLED_ADDR = 0x3C;

// Temperature offset calibration (adjust after calibration)
float calibOffset_ET = 0.0;
float calibOffset_BT = 0.0;

// ============================================================================
// GLOBAL VARIABLES
// ============================================================================

String inputBuffer = "";

float lastTemp_ET = 0.0;
float lastTemp_BT = 0.0;
float ambientTemp = 25.0;

bool error_ET = false;
bool error_BT = false;

bool useFahrenheit = false;
bool oledReady = false;

// ============================================================================
// HARDWARE OBJECTS
// ============================================================================

// MAX31855 using software SPI (flexible pin assignment)
Adafruit_MAX31855 thermoET(PIN_SCK, PIN_CS_ET, PIN_MISO);
Adafruit_MAX31855 thermoBT(PIN_SCK, PIN_CS_BT, PIN_MISO);

// SH1106 OLED display
Adafruit_SH1106G display(OLED_WIDTH, OLED_HEIGHT, &Wire, -1);

// ============================================================================
// SETUP
// ============================================================================

void setup() {
  Serial.begin(BAUD_RATE);

  // Initialize MAX31855 modules
  if (!thermoET.begin()) { error_ET = true; }
  if (!thermoBT.begin()) { error_BT = true; }

  // Initialize OLED display
  if (display.begin(OLED_ADDR, true)) {
    oledReady = true;
    display.clearDisplay();
    display.display();           // flush zeros to display RAM
    delay(100);                  // let the controller settle
    display.setTextSize(1);
    display.setTextColor(SH110X_WHITE);
    display.setCursor(0, 0);
    display.println(F("Milk Depot Roaster"));
    display.println(F("2-Channel TC4"));
    display.println();
    display.println(F("Waiting for Artisan"));
    display.display();
  }

  // Startup message (comment lines ignored by Artisan)
  Serial.println(F("# Milk Depot Coffee Roaster"));
  Serial.println(F("# TC4 Emulator - 2 Channel"));
  Serial.println(F("# Channels: ET, BT"));
  Serial.println(F("# Baud: 115200"));
  Serial.print(F("# ET init: "));
  Serial.println(error_ET ? F("FAIL") : F("OK"));
  Serial.print(F("# BT init: "));
  Serial.println(error_BT ? F("FAIL") : F("OK"));
  Serial.print(F("# OLED: "));
  Serial.println(oledReady ? F("OK") : F("FAIL"));
}

// ============================================================================
// MAIN LOOP
// ============================================================================

void loop() {
  while (Serial.available() > 0) {
    char c = Serial.read();

    if (c == '\n' || c == '\r') {
      if (inputBuffer.length() > 0) {
        handleCommand(inputBuffer);
        inputBuffer = "";
      }
    } else {
      inputBuffer += c;
    }
  }
}

// ============================================================================
// COMMAND HANDLER
// ============================================================================

void handleCommand(String cmd) {
  cmd.toUpperCase();
  cmd.trim();

  if (cmd.startsWith("READ")) {
    sendTemperatures();
  }
  else if (cmd.startsWith("DIAG")) {
    // Raw diagnostic: read 32-bit SPI data from each module
    Serial.print(F("# ET internal: "));
    Serial.println(thermoET.readInternal(), 2);
    Serial.print(F("# ET celsius: "));
    Serial.println(thermoET.readCelsius(), 2);
    Serial.print(F("# ET error: "));
    Serial.println(thermoET.readError());
    Serial.println();
    Serial.print(F("# BT internal: "));
    Serial.println(thermoBT.readInternal(), 2);
    Serial.print(F("# BT celsius: "));
    Serial.println(thermoBT.readCelsius(), 2);
    Serial.print(F("# BT error: "));
    Serial.println(thermoBT.readError());
  }
  else if (cmd.startsWith("CHAN")) {
    Serial.println(F("# CHAN: 1200 (ET, BT, unused, unused)"));
  }
  else if (cmd.startsWith("UNITS")) {
    if (cmd.indexOf('F') >= 0) {
      useFahrenheit = true;
      Serial.println(F("# Units: Fahrenheit"));
    } else {
      useFahrenheit = false;
      Serial.println(F("# Units: Celsius"));
    }
  }
  else if (cmd.startsWith("FILT")) {
    Serial.println(F("# FILT: acknowledged"));
  }
  else if (cmd.startsWith("OT1") || cmd.startsWith("OT2")) {
    // No outputs to control
  }
  else if (cmd.startsWith("IO3")) {
    // Acknowledge
  }
  else if (cmd.startsWith("PID")) {
    Serial.println(F("# PID: acknowledged"));
  }
}

// ============================================================================
// TEMPERATURE READING
// ============================================================================

void sendTemperatures() {
  float tempET = readTemperature_ET();
  float tempBT = readTemperature_BT();

  // Read ambient from ET module's cold junction
  float amb = thermoET.readInternal();
  if (!isnan(amb)) {
    ambientTemp = amb;
  }

  lastTemp_ET = tempET;
  lastTemp_BT = tempBT;

  if (useFahrenheit) {
    tempET = celsiusToFahrenheit(tempET);
    tempBT = celsiusToFahrenheit(tempBT);
  }

  // TC4 response: ambient,chan1,chan2,chan3,chan4
  Serial.print(ambientTemp, 2);
  Serial.print(",");
  Serial.print(tempET, 2);      // Channel 1 = ET
  Serial.print(",");
  Serial.print(tempBT, 2);      // Channel 2 = BT
  Serial.print(",");
  Serial.print("0.00");         // Channel 3 = unused
  Serial.print(",");
  Serial.println("0.00");       // Channel 4 = unused

  updateDisplay();
}

float readTemperature_ET() {
  float temp = thermoET.readCelsius();
  uint8_t err = thermoET.readError();
  if (isnan(temp)) {
    error_ET = true;
    Serial.print(F("# ET err: "));
    if (err & 0x01) Serial.print(F("OPEN "));
    if (err & 0x02) Serial.print(F("SHORT_GND "));
    if (err & 0x04) Serial.print(F("SHORT_VCC "));
    if (err == 0) Serial.print(F("NaN_NO_ERR_BITS "));
    Serial.println();
    return lastTemp_ET;
  }
  error_ET = false;
  return temp + calibOffset_ET;
}

float readTemperature_BT() {
  float temp = thermoBT.readCelsius();
  uint8_t err = thermoBT.readError();
  if (isnan(temp)) {
    error_BT = true;
    Serial.print(F("# BT err: "));
    if (err & 0x01) Serial.print(F("OPEN "));
    if (err & 0x02) Serial.print(F("SHORT_GND "));
    if (err & 0x04) Serial.print(F("SHORT_VCC "));
    if (err == 0) Serial.print(F("NaN_NO_ERR_BITS "));
    Serial.println();
    return lastTemp_BT;
  }
  error_BT = false;
  return temp + calibOffset_BT;
}

// ============================================================================
// UTILITY FUNCTIONS
// ============================================================================

float celsiusToFahrenheit(float celsius) {
  return (celsius * 9.0 / 5.0) + 32.0;
}

// ============================================================================
// OLED DISPLAY
// ============================================================================

void updateDisplay() {
  if (!oledReady) return;

  display.clearDisplay();
  display.setTextSize(1);
  display.setCursor(0, 0);

  display.println(F("MILK DEPOT ROASTER"));
  display.println(F("------------------"));
  display.println();

  // ET reading
  display.print(F("ET: "));
  if (error_ET) {
    display.println(F("--- ERR"));
  } else {
    display.print(lastTemp_ET, 1);
    display.println(F(" C"));
  }

  // BT reading
  display.print(F("BT: "));
  if (error_BT) {
    display.println(F("--- ERR"));
  } else {
    display.print(lastTemp_BT, 1);
    display.println(F(" C"));
  }

  display.println();
  display.print(F("Amb: "));
  display.print(ambientTemp, 1);
  display.println(F(" C"));

  display.display();
}

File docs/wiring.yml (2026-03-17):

# Milk Depot Coffee Roaster - Wiring Harness
# 2-Channel Thermocouple System
# Arduino Nano + 2x MAX31855 (SPI) + 1.3" OLED (I2C)
#
# Generate: wireviz docs/wiring.yml
# Output:   docs/wiring.png, docs/wiring.svg, docs/wiring.html

connectors:
  Nano:
    type: Arduino Nano (USB-C)
    subtype: male
    pinlabels: [D13, D12, D10, D9, A4, A5, 5V, GND, USB-C]
    notes: Powered via USB from RPi 4

  BT:
    type: MAX31855 Module
    subtype: female
    pinlabels: [VCC, GND, SCK, DO, CS, TC+, TC-]
    notes: Bean Temperature

  ET:
    type: MAX31855 Module
    subtype: female
    pinlabels: [VCC, GND, SCK, DO, CS, TC+, TC-]
    notes: Exhaust Temperature

  OLED:
    type: 1.3" SH1106 OLED
    subtype: female
    pinlabels: [VCC, GND, SDA, SCL]
    notes: 128x64 I2C display

  TC_BT:
    type: K-Type Thermocouple
    subtype: male
    pinlabels: ["+", "-"]
    notes: "35mm/2.5mm probe, bare tinned wire, red=negative"

  TC_ET:
    type: K-Type Thermocouple
    subtype: male
    pinlabels: ["+", "-"]
    notes: "50mm/3.0mm probe, bare tinned wire, red=negative"

  C1:
    type: Ceramic Capacitor
    subtype: male
    pinlabels: ["1", "2"]
    notes: 100nF (104) decoupling, across BT VCC/GND

  C2:
    type: Ceramic Capacitor
    subtype: male
    pinlabels: ["1", "2"]
    notes: 100nF (104) decoupling, across ET VCC/GND

  RPi:
    type: Raspberry Pi 4
    subtype: female
    pinlabels: [USB]
    notes: Artisan software, 10.0.10.102

cables:
  W1:
    wirecount: 1
    colors: [YE]
    notes: SPI Clock to BT

  W2:
    wirecount: 1
    colors: [YE]
    notes: SPI Clock to ET

  W3:
    wirecount: 1
    colors: [GN]
    notes: SPI Data from BT

  W4:
    wirecount: 1
    colors: [GN]
    notes: SPI Data from ET

  W5:
    wirecount: 1
    colors: [BU]
    notes: CS Bean Temp (D10)

  W6:
    wirecount: 1
    colors: [VT]
    notes: CS Exhaust Temp (D9)

  W7:
    wirecount: 1
    colors: [WH]
    notes: I2C SDA

  W8:
    wirecount: 1
    colors: [OG]
    notes: I2C SCL

  W9:
    wirecount: 1
    colors: [RD]
    notes: 5V to BT module

  W10:
    wirecount: 1
    colors: [RD]
    notes: 5V to ET module

  W11:
    wirecount: 1
    colors: [RD]
    notes: 5V to OLED

  W12:
    wirecount: 1
    colors: [BK]
    notes: GND to BT module

  W13:
    wirecount: 1
    colors: [BK]
    notes: GND to ET module

  W14:
    wirecount: 1
    colors: [BK]
    notes: GND to OLED

  W15:
    wirecount: 2
    colors: [YE, RD]
    length: 1.5 m
    notes: "BT thermocouple lead (red=negative!)"

  W16:
    wirecount: 2
    colors: [YE, RD]
    length: 1.5 m
    notes: "ET thermocouple lead (red=negative!)"

  C1a:
    wirecount: 1
    colors: [RD]
    notes: Cap C1 to BT VCC

  C1b:
    wirecount: 1
    colors: [BK]
    notes: Cap C1 to BT GND

  C2a:
    wirecount: 1
    colors: [RD]
    notes: Cap C2 to ET VCC

  C2b:
    wirecount: 1
    colors: [BK]
    notes: Cap C2 to ET GND

  USB:
    wirecount: 1
    colors: [BK]
    length: 2 m
    notes: USB-C cable to RPi

connections:
  # SPI Clock
  -
    - Nano: D13
    - W1: 1
    - BT: SCK
  -
    - Nano: D13
    - W2: 1
    - ET: SCK

  # SPI Data
  -
    - Nano: D12
    - W3: 1
    - BT: DO
  -
    - Nano: D12
    - W4: 1
    - ET: DO

  # Chip Selects
  -
    - Nano: D10
    - W5: 1
    - BT: CS
  -
    - Nano: D9
    - W6: 1
    - ET: CS

  # I2C
  -
    - Nano: A4
    - W7: 1
    - OLED: SDA
  -
    - Nano: A5
    - W8: 1
    - OLED: SCL

  # 5V Power
  -
    - Nano: 5V
    - W9: 1
    - BT: VCC
  -
    - Nano: 5V
    - W10: 1
    - ET: VCC
  -
    - Nano: 5V
    - W11: 1
    - OLED: VCC

  # Ground
  -
    - Nano: GND
    - W12: 1
    - BT: GND
  -
    - Nano: GND
    - W13: 1
    - ET: GND
  -
    - Nano: GND
    - W14: 1
    - OLED: GND

  # Thermocouples
  -
    - TC_BT: ["+", "-"]
    - W15: [1, 2]
    - BT: [TC+, TC-]
  -
    - TC_ET: ["+", "-"]
    - W16: [1, 2]
    - ET: [TC+, TC-]

  # Decoupling caps (100nF across VCC/GND on each MAX31855)
  -
    - BT: VCC
    - C1a: 1
    - C1: "1"
  -
    - BT: GND
    - C1b: 1
    - C1: "2"
  -
    - ET: VCC
    - C2a: 1
    - C2: "1"
  -
    - ET: GND
    - C2b: 1
    - C2: "2"

  # USB to RPi
  -
    - RPi: USB
    - USB: 1
    - Nano: USB-C

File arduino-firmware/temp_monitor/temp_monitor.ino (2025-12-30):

/*
 * Milk Depot Coffee Roaster - Temperature Monitor (3-Channel)
 *
 * Continuous output firmware for reading three temperature probes:
 *   - ET (Exhaust/Environment Temperature)
 *   - BT (Bean Temperature)
 *   - FT (Flame Temperature)
 *
 * Sends temperature data over serial in a simple comma-separated format.
 * For use with External Program device type in Artisan or custom parsers.
 *
 * For TC4 protocol compatibility (ArduinoTC4 device type), use tc4_emulator instead.
 *
 * Hardware:
 *   - 3x MAX31855 thermocouple amplifier modules (SPI)
 *   - 3x Olimex TC-K-TYPE-1.5M K-type thermocouples
 *
 * Author: Jason
 * Repository: https://github.com/jasonvanwyk/Milk-Depot-Coffee-Roaster
 */

#include <SPI.h>

// Uncomment when MAX31855 library is installed:
// #include <Adafruit_MAX31855.h>

// ============================================================================
// CONFIGURATION
// ============================================================================

const unsigned long BAUD_RATE = 115200;
const unsigned long SAMPLE_INTERVAL_MS = 1000;  // Send data every 1 second

// SPI Pin Definitions (shared bus)
const int PIN_SCK  = 13;   // SPI Clock (shared)
const int PIN_MISO = 12;   // SPI Data Out (shared)

// Chip Select pins (directly controlled, active low)
const int PIN_CS_ET = 10;  // CS for Exhaust Temperature
const int PIN_CS_BT = 9;   // CS for Bean Temperature
const int PIN_CS_FT = 8;   // CS for Flame Temperature

// Temperature offset calibration (adjust after calibration)
float calibOffset_ET = 0.0;
float calibOffset_BT = 0.0;
float calibOffset_FT = 0.0;

// ============================================================================
// MAX31855 OBJECTS (uncomment when library installed)
// ============================================================================

// Adafruit_MAX31855 thermoET(PIN_SCK, PIN_CS_ET, PIN_MISO);
// Adafruit_MAX31855 thermoBT(PIN_SCK, PIN_CS_BT, PIN_MISO);
// Adafruit_MAX31855 thermoFT(PIN_SCK, PIN_CS_FT, PIN_MISO);

// ============================================================================
// GLOBAL VARIABLES
// ============================================================================

unsigned long lastSampleTime = 0;

// Last good readings (returned on error)
float lastTemp_ET = 0.0;
float lastTemp_BT = 0.0;
float lastTemp_FT = 0.0;

// ============================================================================
// SETUP
// ============================================================================

void setup() {
  Serial.begin(BAUD_RATE);

  // Wait for serial port to connect (needed for some boards)
  while (!Serial) {
    ;
  }

  // Configure CS pins as outputs
  pinMode(PIN_CS_ET, OUTPUT);
  pinMode(PIN_CS_BT, OUTPUT);
  pinMode(PIN_CS_FT, OUTPUT);

  // Deselect all MAX31855 modules
  digitalWrite(PIN_CS_ET, HIGH);
  digitalWrite(PIN_CS_BT, HIGH);
  digitalWrite(PIN_CS_FT, HIGH);

  // Initialize SPI
  SPI.begin();

  // Send startup message
  Serial.println(F("# Milk Depot Coffee Roaster - 3 Channel Temperature Monitor"));
  Serial.println(F("# Format: ET:xxx.x,BT:xxx.x,FT:xxx.x"));
  Serial.println(F("# Baud: 115200, Interval: 1000ms"));
}

// ============================================================================
// MAIN LOOP
// ============================================================================

void loop() {
  unsigned long currentTime = millis();

  if (currentTime - lastSampleTime >= SAMPLE_INTERVAL_MS) {
    lastSampleTime = currentTime;

    // Read all temperatures
    float tempET = readTemperature_ET();
    float tempBT = readTemperature_BT();
    float tempFT = readTemperature_FT();

    // Store last good readings
    lastTemp_ET = tempET;
    lastTemp_BT = tempBT;
    lastTemp_FT = tempFT;

    // Output format: ET:xxx.x,BT:xxx.x,FT:xxx.x
    Serial.print(F("ET:"));
    Serial.print(tempET, 1);
    Serial.print(F(",BT:"));
    Serial.print(tempBT, 1);
    Serial.print(F(",FT:"));
    Serial.println(tempFT, 1);
  }
}

// ============================================================================
// TEMPERATURE READING FUNCTIONS
// ============================================================================

float readTemperature_ET() {
  // WITH MAX31855 LIBRARY (uncomment when hardware connected):
  // float temp = thermoET.readCelsius();
  // if (isnan(temp)) return lastTemp_ET;
  // return temp + calibOffset_ET;

  // SIMULATION MODE:
  return readAnalogSimulated(A0);
}

float readTemperature_BT() {
  // WITH MAX31855 LIBRARY:
  // float temp = thermoBT.readCelsius();
  // if (isnan(temp)) return lastTemp_BT;
  // return temp + calibOffset_BT;

  // SIMULATION MODE:
  return readAnalogSimulated(A1);
}

float readTemperature_FT() {
  // WITH MAX31855 LIBRARY:
  // float temp = thermoFT.readCelsius();
  // if (isnan(temp)) return lastTemp_FT;
  // return temp + calibOffset_FT;

  // SIMULATION MODE:
  return readAnalogSimulated(A2);
}

// Simulated reading from analog noise (for testing without hardware)
float readAnalogSimulated(int analogPin) {
  int raw = analogRead(analogPin);
  float voltage = raw * (5.0 / 1023.0);
  return voltage * 50.0;  // ~0-250C range
}

// ============================================================================
// HARDWARE ACTIVATION INSTRUCTIONS
// ============================================================================

/*
 * TO ENABLE MAX31855 THERMOCOUPLES:
 *
 * 1. Install Adafruit MAX31855 library via Arduino IDE Library Manager
 *
 * 2. Uncomment: #include <Adafruit_MAX31855.h>
 *
 * 3. Uncomment the thermocouple object declarations
 *
 * 4. In each readTemperature_XX function:
 *    - Uncomment the MAX31855 code block
 *    - Comment out/delete the readAnalogSimulated() call
 *
 * 5. Compile and upload
 *
 * WIRING:
 *   MAX31855 modules share SCK (D13) and MISO (D12)
 *   Each has unique CS: ET->D10, BT->D9, FT->D8
 *   All powered from 5V and GND
 */

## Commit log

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2025-11-10 Add Arduino CLI support and development tools
    - Install Arduino CLI v1.3.1 locally in bin/
    - Configure Arduino AVR core v1.8.6 for UNO R3
    - Install Adafruit MAX31855 library and dependencies
    - Create helper scripts for common operations:
    - compile.sh - Compile Arduino sketches
    - upload.sh - Upload firmware to Arduino
    - monitor.sh - Monitor serial output
    - detect.sh - Detect connected Arduino boards
    - Add comprehensive Arduino CLI documentation (ARDUINO_CLI.md)
    - Create serial test sketch for troubleshooting
    - Add Python serial monitor script (test_serial.py)
    - Document hardware troubleshooting (garbled output issue)
    This enables direct Arduino development from the Raspberry Pi witho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
    [test_serial.py]
2025-11-10 ✅ Confirm system fully operational - serial communication working perfectly
    BREAKTHROUGH: Arduino and firmware are working flawlessly!
    What we discovered:
    - Previous "garbled" output was terminal display issue, not hardware
    - Arduino is sending perfect formatted data: BT:xx.x,DT:xx.x
    - Serial communication at 115200 baud is 100% functional
    - Current readings (~63-66°C) are from floating analog pins (no sensors yet)
    Test Results (2025-11-10 13:15):
    ```
    BT:63.0,DT:63.0
    BT:62.8,DT:62.6
    BT:63.0,DT:63.0
    BT:64.8,DT:64.8
    BT:66.2,DT:66.0
    BT:66.5,DT:66.0
    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
2025-11-10 Add flexible Arduino serial reader script
    - Create read_arduino.py for reading Arduino output at any baud rate
    - Usage: python3 read_arduino.py [baudrate]
    - Defaults to 9600 baud
    - Better error handling and user feedback
    - Successfully tested with AnalogReadSerial example
    Verified working with both 9600 and 115200 baud rates.
    [read_arduino.py]
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2025-12-30 Upgrade to 3-channel thermocouple system with MAX31855
    Major revision adding support for 3 temperature probes:
    - ET (Exhaust Temperature) - Channel 1
    - BT (Bean Temperature) - Channel 2
    - FT (Flame Temperature) - Channel 3
    Hardware changes:
    - 3x MAX31855 thermocouple amplifiers via SPI
    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
    [thermocouples__temperature_probes.csv]
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2026-02-23 Restructure project to standard Precept project template
    Reorganize project directory structure to match the ICT project template:
    - Move all technical docs into docs/ directory
    - Add assets/ with Precept branding (logo, company details, email signature)
    - Add correspondence/ with supplier correspondence log
    - Create STATUS.md with full project tracking and financials
    - Create RESUME.md for quick session context
    - Rewrite README.md in standard template format
    - Update CLAUDE.md with new file paths and project structure
    - Remove cruft (error.text, empty artisan-source/, outdated CURRENT_STATUS.md)
    - Add credentials.txt to .gitignore
    [thermocouples__temperature_probes.csv]
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2026-03-13 Add KiCad schematic, OLED bezel design, and component photos
    - Create KiCad schematic for actual components: Arduino Nano, 2x MAX31855, OLED, 100nF caps
    - Add programmatic schematic generator (kicad/generate_schematic.py)
    - Design snap-fit OLED bezel in OpenSCAD (3d-prints/oled-bezel.scad)
    - Add component photos (Arduino Nano, MAX31855 modules, OLED display, capacitors)
    - Update .gitignore for KiCad lock files
    - Update RESUME.md and STATUS.md with session progress
    [milk-depot-coffee-roaster.kicad_sch, oled-bezel.scad]
2026-03-13 Add OLED bezel renders and FreeCAD redesign with caliper measurements
    - Rendered OpenSCAD bezel: STL export + 4-angle PNG previews
    - Redesigned bezel in FreeCAD with real caliper-verified OLED measurements
    - FreeCAD WIP: PCB outline, bezel face pad, window cutout positioned correctly
    - Added draw_bezel.py helper script for FreeCAD console
    - Updated RESUME.md and STATUS.md with session progress
    [oled-1.3inch-holder.FCStd, oled-bezel.stl]
2026-03-16 Add OLED back piece design and Printables mounting frame for test print
    - FreeCAD back piece: frame with corner bosses and 3.2mm fastener holes
    - Export bezel front piece (STL + 3MF)
    - Add Printables OLED mounting frame (werner_rh) as alternative design
    - Test print of display-testpanel.stl sent to Bambu X1 in PETG-CF
    [display-testpanel.stl, display-washer.stl, displayframe-oled-1_3inch-sh1106.stl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]
2026-03-17 Add wiring documentation suite — WireViz, Fritzing, and WIRING.md rewrite
    - Create WireViz YAML wiring diagram with all connections + decoupling caps
    - Rewrite docs/WIRING.md for 2-channel Nano design (was 3-channel UNO R3)
    - Add Adafruit Fritzing parts for MAX31855 and 1.3" OLED
    - Export FreeCAD bezel front piece to STL (with chamfers)
    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
    [oled-1.3inch-holder-bezel-BodyChamfer007.stl, oled-1.3inch-holder-bezel.FCStd, wiring.bom.tsv]
2026-03-19 Update firmware for 2-channel Nano and pivot to ESP32 redesign
    - Enable MAX31855 hardware + SH1106 OLED in tc4_emulator firmware
    - Remove 3rd channel (FT), update for Arduino Nano target
    - Add DIAG command for MAX31855 error reporting
    - Knockoff MAX31855 module smoked — redesigning with genuine parts
    - New plan: ESP32-WROOM-32E + MAX31855KASA+ on custom PCB + 2.42" OLED
    [tc4_emulator.ino]
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2026-03-21 Rewrite BOM v2.0 for ESP32 redesign with specific 0805 part numbers
    - Complete BOM rewrite: ESP32 + genuine MAX31855KASA+ + Adafruit 2719 OLED
    - All 0805 passives with specific MPNs matched to DigiKey cart
    - Cross-referenced Fairfield combined order — only screw terminals + OLED still short
    - Selected Adafruit 2719 (SSD1305) over Waveshare SSD1309 for quality + standard header
    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
2026-03-23 Update project tracking for OLED → LCD display switch
    Switched from Adafruit 2.42" OLED (SSD1305) to Keyestudio 20×4 I2C LCD
    (MD0074, HD44780 + PCF8574) — simpler driver, no burn-in risk, better
    readability in roasting environment. Added BSS138 level shifters for
    3.3V/5V I2C on custom PCB. Decided MAX31855 breakout board first to
    validate thermocouples before full system PCB design.
2026-03-30 Scaffold new KiCad 10 project for ESP32 redesign
    - Archive old Arduino Nano schematic to kicad/archive/v1-nano/
    - New project with JLCPCB-compatible design rules (2-layer, A3 schematic)
    - Place ESP32-WROOM-32E, 2× MAX31855KASA, 2× BSS138 symbols (validated against datasheets)
    - Set up project-local symbol/footprint libraries and BOM fields (MPN, DigiKey_PN)
    - Add component datasheets (ESP32, MAX31855, BSS138, LCD)
    - Update .gitignore for KiCad 10 patterns
    - Update RESUME.md and STATUS.md with procurement and schematic progress
    [milk-depot-coffee-roaster.kicad_pcb, milk-depot-coffee-roaster.kicad_sch]
2026-03-30 Verify procurement and add component datasheets for schematic capture
    - Audit all supplier invoices, correct stale BOM references (DK #122017091 was fully returned)
    - Download datasheets for NCP1117, MMBT2222A, TL3342, OSTTC020162, DG127, B4B-PH-K-S, caps
    - Place R1-R6 and C1 with BOM fields (MPN, Manufacturer, DigiKey_PN)
    - Remove old generate_schematic.py (was for archived Nano schematic)
    - Update RESUME.md and STATUS.md with verified procurement status
    [milk-depot-coffee-roaster.kicad_sch]
2026-04-21 Scaffold MD-TC-BRK v1.0 breakout sub-project from SparkFun DEV-13266
    Eagle .sch/.brd vendored into kicad/breakout-max31855/eagle-source/
    ready for KiCad 10 File -> Import -> Non-KiCad conversion. Topology
    locked in companion tool repo (kicad-coffee-roaster session 2): the
    all-in-one ESP32 PCB plan is dropped, replaced by 3x custom MAX31855
    breakouts plus an Arduino Nano 5V stripboard. Only the breakout is
    fabbed; stripboard is hand-assembled.
    README documents the 5 planned forks (MAX31855K->KASA+ footprint,
    DG127 screw terminal, 0603->0805 passives, DNP EMI/TVS/chassis-bond
    footprints, silkscreen + title block) and the CC-BY-SA 4.0
    derivative-licence obligations.
    Upstream LICENSE preserved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
    [SparkFun_Thermocouple_Breakout.brd, SparkFun_Thermocouple_Breakout.sch]
2026-04-21 Apply phase 2 post-import cleanup to breakout-max31855
    De-nest project files from KiCad's default import layout (single dir
    now, not nested breakout-max31855/breakout-max31855/).
    Rename SparkFun_Thermocouple_Breakout.* project files to
    breakout-max31855.* to match MD-TC-BRK v1.0 naming. The auto-generated
    -eagle-import symbol library keeps its original filename for provenance
    and to avoid rewriting hundreds of embedded lib_id references in the
    schematic; that library will shrink over time as the 5 planned forks
    replace Eagle symbols with milk-depot equivalents.
    Add KiCad 10 title_block (title, company, rev, date, 3 comment lines
    carrying licence + fork description) and set paper to A4 land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
    [breakout-max31855.kicad_pcb, breakout-max31855.kicad_sch]
2026-04-21 Prune unused eagle-import symbols from breakout schematic cache
    KiCad auto-pruned the embedded (lib_symbols ...) block in
    breakout-max31855.kicad_sch on first open — down from 39,614 lines
    (every symbol in SparkFun's Eagle library, cached by the importer) to
    just the ~15 symbols actually placed on the sheet. File shrinks from
    717 KB to ~50 KB, no functional change.
    Also mirrors sch_revision "1.0-draft" from the title_block into
    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
    [breakout-max31855.kicad_sch]
2026-04-21 Session 4: fresh-draw schematic + BOM sourcing for MD-TC-BRK v1.0
    Replaces the Eagle-imported content with a hand-drawn schematic built on KiCad 10
    stock symbols. Cleaner visual, reviewer-friendly, matches the v1 board's convention.
    - Delete Eagle-imported artefacts: .kicad_pcb, -eagle-import.kicad_sym, sym-lib-table
    - Rewrite breakout-max31855.kicad_sch with 15 placed components (U1, C1-C4, CY1,
    FB1, R1, RB1, D1, J1, JP1, MH1, SJ1, TP1) + 4 power/flag symbols
    - Assign footprints, set DNP flags on C3/C4/D1/CY1
    - Add Manufacturer, MPN, Supplier, Supplier_PN properties to 12 orderable components
    for direct BOM export to DigiKey/Mantech
    - Power net renamed VCC -> +3V3 (voltage-explicit, pr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
    [breakout-max31855.kicad_pcb, breakout-max31855.kicad_sch]
2026-09-30 Session 6: reset direction to T-Display-S3 + 4-channel isolated board
    The project notes here had drifted from the April breakout sessions kept
    in the companion tool repo, so the next step was unclear after a
    five-month gap. Reconcile them and record the new direction.
    - Choose LilyGO T-Display-S3 over Nano/stripboard and bare ESP32 + LCD
    - Replace three breakouts with one 4-channel board, isolated per channel,
    because grounded probes would cause false faults on a shared island
    - Record the DigiKey isolation parts order (placed and paid) and the
    design rules in docs/2026-09-30-tc-board-design-notes.md
    - Add research reports and datasheets for the ordered parts
    - Roll older session notes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
2026-10-02 Schematic session 1: start the 4-channel isolated board in KiCad
    Jason draws the schematic himself, so the project starts from a
    generated, unwired starter and each step is checked against the netlist.
    - Add kicad/tc-board-4ch: root sheet plus one channel sheet used four times
    - Add ISO7731DW and RFB-0505S symbols to the shared library
    - Wire island power, isolator and MAX31855 on the channel sheet
    - Keep island nets as local labels so the four islands stay separate
    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
    [channel.kicad_sch, tc-board-4ch.kicad_sch]
2026-10-07 Schematic session 2: 4-channel isolated board ERC-clean
    - Channel sheet: probe input chain (TVS, ferrite, 1 nF, 10 nF differential)
    - Root sheet: sheet pins, host connector, 5V entry, SN74AHC125 MISO buffer,
    button connector, PWR_FLAGs
    - ERC reports zero violations on all five sheets
    - Roll the 2 Oct session into the archive; next step is the footprint check
    and PCB layout
    [channel.kicad_sch, tc-board-4ch.kicad_sch]
2026-10-07 Pre-layout session: footprints verified, DG127 footprint added, chassis network dropped
    - Confirm the Traco TMA footprint matches the RFB-0505S drawing so the DC-DC
    pads can be trusted; JST PH, header, tantalum, TVS and ferrite also pass
    - Add a true-outline Degson DG127 screw-terminal footprint and box 3D model
    because the Phoenix stand-in drew the body 4 mm too deep for edge placement
    - Track the project's own hand-written 3D models despite the vendor-model ignore
    - Leave the chassis network out: grounded-junction probes already reference
    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
    [channel.kicad_sch]
2026-10-08 Layout session 1: board set up, all parts placed, slots and holes in
    - Net classes ISO1-ISO4 with wildcard patterns and a custom .kicad_dru
    enforcing a 2 mm gap between each island and everything else, so DRC
    guards the isolation barrier instead of relying on eyeballing
    - 82 footprints placed by script at a 22 mm channel pitch; isolator and
    DC-DC straddle one barrier line so the slot runs under both, and the
    MAX31855 is rotated to put its SPI pads directly below the isolator's
    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
    [tc-board-4ch.kicad_pcb]
2026-10-08 Layout session 2: ground zones in, fills verified, DRC clean on copper
    - Five multi-layer zones: host GND strip and four GND_ISO islands, 0.3
    clearance, thermal reliefs; 2 mm bare gap between islands, slots
    between host and islands
    - Fills checked by refilled scratch copy and SVG export; 0 clearance,
    isolation or edge violations
    - Five starved-thermal errors on isolator GND1 pins and C105 noted, to
    clear with the GND tie tracks during routing
    - Layout session 1 rolled into docs/archive; routing channel 1 is next
    [tc-board-4ch.kicad_pcb]
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2026-10-08 Layout session 4: host routing plan generated and DRC-clean on a scratch copy
    - host-routing.py moves five parts (U1, C3, C1, C2, J2) and injects
    75 tracks + 37 vias for the 37 host connections; kicad-cli DRC on the
    scratch copy reports 0 copper errors and 0 unconnected
    - Scripting the geometry replaced reasoning it out, which had stalled
    the previous session
    - Plan document with move table, lane table and per-net step list
    - Not yet applied to the real board; Jason to choose GUI or script
2026-10-09 Layout session 5: host routing applied to the real board, verified beyond DRC
    - Ran host-routing.py on the real board with the editor closed: 5 part
    moves, 75 tracks, 37 vias; 0 unconnected, 0 copper errors, fills saved
    - Verified independently of DRC: netlist parity 276/276, net classes,
    isolation rules proven by planted tracks, zone recess 2.0 mm, measured
    island gaps 2.0/3.0 mm, trace current margin
    - kicad-cli 10.0.6 DRC reports nothing for a track inside a foreign pad;
    add geom-audit.py and zone-audit.py to cover that, both validated with
    planted defects and clean on the real board
    - Roll layout session 4 into the archive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
    [tc-board-4ch.kicad_pcb]
2026-10-09 Correct the DRC finding: no pad-overlap blind spot, planted tracks get re-netted
    KiCad assigns a floating track's net from the pad it touches on load, so
    the planted test could never fail. A real track drawn between two pads of
    different nets is reported as shorting_items, solder_mask_bridge and
    tracks_crossing. Audit scripts stay as a second opinion. Note 10.0.7's
    zone-fill fixes pending in Arch.
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2026-10-16 Log UPS customs clearance for the hot plate shipment
    Record what UPS charged (R362.25), why it was owed despite "free
    delivery", the payment and the importer documents sent, so the landed
    cost can be finalised when the final UPS invoice arrives.
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

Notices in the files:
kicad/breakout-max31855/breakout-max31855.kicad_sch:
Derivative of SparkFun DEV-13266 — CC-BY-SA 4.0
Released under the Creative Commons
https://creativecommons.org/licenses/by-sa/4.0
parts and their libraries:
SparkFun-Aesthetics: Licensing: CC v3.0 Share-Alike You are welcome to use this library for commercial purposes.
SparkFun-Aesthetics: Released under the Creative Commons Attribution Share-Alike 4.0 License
